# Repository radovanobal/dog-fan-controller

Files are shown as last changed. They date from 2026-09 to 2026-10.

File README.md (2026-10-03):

# Dog Fan Controller

A PWM controller for two Noctua NF-A14 PWM fans, using an ESP32-C3 SuperMini
and an external SHT4x temperature and humidity sensor.

## Licence and attribution

Copyright © 2026 **Appicanis, Radovan Obal s.p.**

The original hardware design and accompanying design documentation are
licensed under **CERN-OHL-P-2.0**. See [LICENSE](LICENSE) for the complete
licence and [NOTICE](NOTICE) for attribution, source location and scope.

You may use, modify, manufacture and sell the design, including commercially.
You do not have to publish your modifications. When redistributing design
materials, retain the applicable notices and provide the licence; when
redistributing modified design materials, also identify and date your changes.
When supplying physical products, ensure recipients can access the applicable
notices, as required by section 4 of the licence. We impose no additional
requirement for prominent branding or credit on a product or sales page.

Original design: **Appicanis, Radovan Obal s.p.**  
Source: <https://github.com/radovanobal/dog-fan-controller>

Third-party materials retain their own licences. Firmware and standalone
software require their own explicit licence; the hardware licence above
does not automatically apply to them.

## Open on another machine

Install **KiCad 10** with its standard symbol, footprint and 3D model libraries,
clone this repository, then open `Fan Controller.kicad_pro` in KiCad.
No personal library configuration or custom path variables are required.

The project library tables explicitly reference KiCad's standard libraries using
`KICAD10_SYMBOL_DIR` and `KICAD10_FOOTPRINT_DIR`. Custom dependencies are included
in `custom_footprints.pretty/`, `Fan_Controller.pretty/`, `symbols/` and
`3dmodels/`, and use `${KIPRJMOD}` paths relative to the checkout. The two
root-level symbol libraries are also registered in the project table. Standard
3D models use KiCad's `KICAD10_3DMODEL_DIR` setting.

When adding a custom part, include its symbol, footprint and any 3D model in the
repository and update the project library tables. Avoid absolute paths or
libraries registered only in your personal KiCad settings.

## Manufacturing preparation

JLCPCB fabrication and draft assembly outputs, order settings and review status
are in [manufacturing/jlcpcb](manufacturing/jlcpcb/README.md). Regenerate exports
with `python3 tools/prepare_jlcpcb.py` using KiCad 10.

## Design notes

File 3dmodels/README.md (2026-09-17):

# Custom library assets

The custom footprints, symbol libraries and STEP models bundled with this project
were copied from the existing design's local KiCad libraries on 2026-09-17.
Existing creator and manufacturer metadata are retained in the library files.
The normalized project-local fuse symbol is retained. Imported symbol default
footprint names now resolve through the project library table. Footprint model
assignments and transforms were copied from the PCB, with paths made relative to
`${KIPRJMOD}`. PCB placement, routing and model transforms are unchanged.

These third-party assets retain their original licences and notices, as described
in the repository's NOTICE; bundling does not relicense them under CERN-OHL-P-2.0.
The original local files did not include separate licence files.

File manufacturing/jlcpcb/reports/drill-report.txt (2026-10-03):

Drill report for Fan Controller.kicad_pcb
Created on 2026-09-17T20:02:06

Copper Layer Stackup:
    =============================================================
    L1 :  F.Cu                      front
    L2 :  In1.Cu                    in1
    L3 :  In2.Cu                    in2
    L4 :  B.Cu                      back

Drill file 'Fan Controller-PTH.drl' contains
    plated through holes:
    =============================================================
    T1  0.300mm  0.0118"  (38 holes))
    T2  0.750mm  0.0295"  (19 holes))
    T3  0.840mm  0.0331"  (16 holes))
    T4  1.000mm  0.0394"  (2 holes))
    T5  1.067mm  0.0420"  (8 holes))
    T6  1.550mm  0.0610"  (2 holes))

    Total plated holes count 85

Drill file 'Fan Controller-NPTH.drl' contains
    unplated through holes:
    =============================================================
    T1  1.295mm  0.0510"  (2 holes))
    T2  2.200mm  0.0866"  (4 holes))
    T3  2.700mm  0.1063"  (1 hole)

    Total unplated holes count 7

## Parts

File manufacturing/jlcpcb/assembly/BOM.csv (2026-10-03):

Comment | Designator | Footprint | LCSC Part # | Manufacturer Part Number | Manufacturer | Quantity
47µF | C1,C8,C9 | C_1210_3225Metric | C84494 | GRM32ER71A476KE15L | Murata | 3
100nF | C2,C4,C5,C13,C18 | C_0805_2012Metric | C1711 | CL21B104KBCNNNC | Samsung Electro-Mechanics | 5
22µF | C3 | CP_Elec_6.3x5.8 | C336302 | EEEHB1V220P | Panasonic | 1
100nF | C7,C14 | C_0603_1608Metric | C1591 | CL10B104KB8NNNC | Samsung Electro-Mechanics | 2
4.7µF | C10 | C_0805_2012Metric | C86040 | GRM21BR71C475KA73L | Murata | 1
10µF | C11,C12 | C_1206_3216Metric | C89632 | CL31B106KBHNNNE | Samsung Electro-Mechanics | 2
22µF / 25V | C15,C16 | C_1210_3225Metric | C3852592 | C1210C226M3RAC7800 | KEMET | 2
56pF C0G | C17 | C_0805_2012Metric | C2277731 | C0805C560G1GACTU | KEMET | 1
47µF / 25V Hybrid | C19 | CP_Elec_6.3x5.8 | C542308 | EEHZC1E470P | Panasonic | 1
SS14 | D1 | D_SMA | C47460 | SS14-E3/61T | Vishay | 1
SMCJ18A | D2 | DIOM7959X262N | C374030 | SMCJ18A | Littelfuse | 1
BZT52C12Q-7-F | D3 | D_SOD-123 | C460785 | BZT52C12Q-7-F | Diodes Inc. | 1
4.7µH | L1 | IND_SPM5030T-4R7M-HZ | C435271 | SPM5030T-4R7M-HZ | TDK | 1
15µH | L2 | IND_SPM6530T-150M-HZ | C307809 | SPM6530T-150M-HZ | TDK | 1
SQD19P06-60L_GE3 | Q1 | TO252AA_SQD19_VIS | C143665 | SQD19P06-60L_GE3 | Vishay | 1
47R | R1,R2 | R_0805_2012Metric | C114541 | RC0805FR-0747RL | Yageo | 2
100k | R3,R4 | R_0805_2012Metric | C96346 | RC0805FR-07100KL | Yageo | 2
1k | R5,R6 | R_0805_2012Metric | C95781 | RC0805FR-071KL | Yageo | 2
10k | R7,R8 | R_0805_2012Metric | C84376 | RC0805FR-0710KL | Yageo | 2
4.7k | R9,R10 | R_0805_2012Metric | C60816 | RC0805FR-074K7L | Yageo | 2
47k | R11 | R_0805_2012Metric | C126351 | RC0805FR-0747KL | Yageo | 1
422k | R12 | R_0805_2012Metric | C273967 | RC0805FR-07422KL | Yageo | 1
30.1k | R13 | R_0805_2012Metric | C163407 | RC0805FR-0730K1L | Yageo | 1
AP63205QWU-7 | U2 | SOT95P280X100-6N | C5248537 | AP63205QWU-7 | Diodes Inc. | 1
SN74LVC2G06DBVR | U3 | SOT-23-6 | C402162 | SN74LVC2G06DBVR | Texas Instruments | 1
AP63201QWU-7 | U4 | SOT95P280X100-6N | C5248535 | AP63201QWU-7 | Diodes Inc. | 1

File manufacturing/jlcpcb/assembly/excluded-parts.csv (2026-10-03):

Designator | Comment | Manufacturer Part Number | LCSC Part # | Reason
F1 | Fuse Holder | 178.6764.0001 |  | DNP in board: excluded from JLCPCB assembly
H1 | MountingHole_2.2mm_M2 |  |  | Mechanical mounting hole
H2 | MountingHole_2.2mm_M2 |  |  | Mechanical mounting hole
H3 | MountingHole_2.2mm_M2 |  |  | Mechanical mounting hole
H4 | MountingHole_2.2mm_M2 |  |  | Mechanical mounting hole
J1 | Power Input | B2B-XH-A (LF) (SN) | C158012 | DNP in board: excluded from JLCPCB assembly
J2 | 4-Pin Fan Header | 470531000 | C240840 | DNP in board: excluded from JLCPCB assembly
J3 | 4-Pin Fan Header | 470531000 | C240840 | DNP in board: excluded from JLCPCB assembly
J4 | I2C | B4B-PH-K-S (LF) (SN) | C131334 | DNP in board: excluded from JLCPCB assembly
J5 | I2C | B4B-PH-K-S (LF) (SN) | C131334 | DNP in board: excluded from JLCPCB assembly
J6 | Expansion 1 | B6B-PH-K-S (LF) (SN) | C131342 | DNP in board: excluded from JLCPCB assembly
J7 | Expansion 2 | B5B-PH-K-S (LF) (SN) | C157993 | DNP in board: excluded from JLCPCB assembly
U1 | ESP32-C3-SuperMini | ESP32-C3-SuperMini |  | DNP in board: excluded from JLCPCB assembly

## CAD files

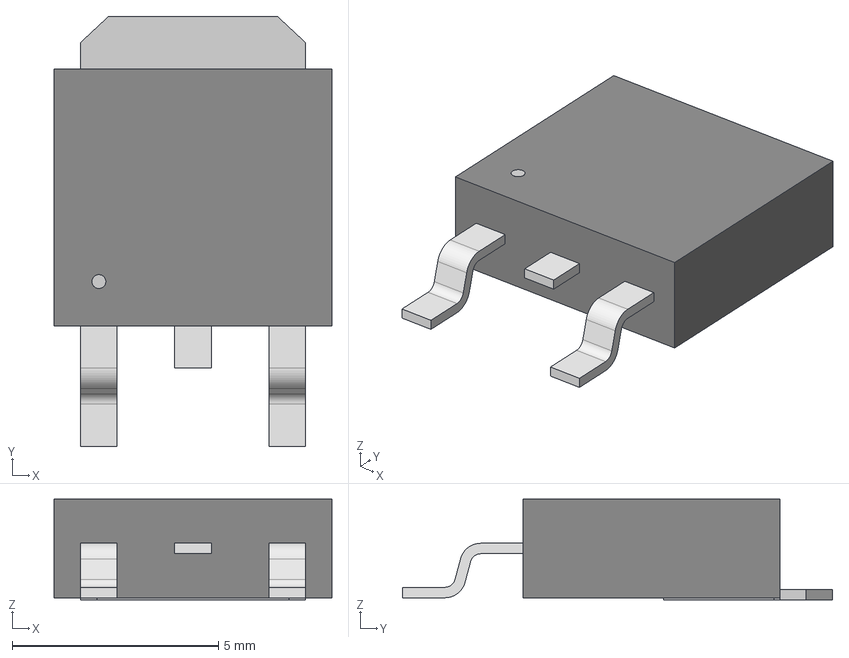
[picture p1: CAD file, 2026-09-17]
3dmodels/TO252AA_SQD19_VIS.step
6.73 x 10.4 x 2.44 mm

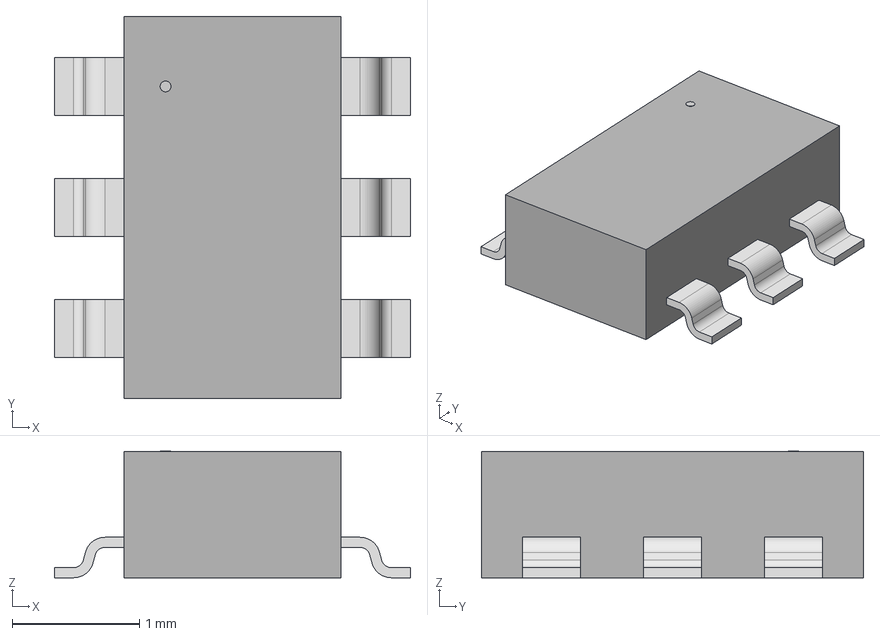
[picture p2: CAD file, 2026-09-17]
3dmodels/SOIC_05WU-7_DIO.step
2.79 x 3.00 x 0.993 mm

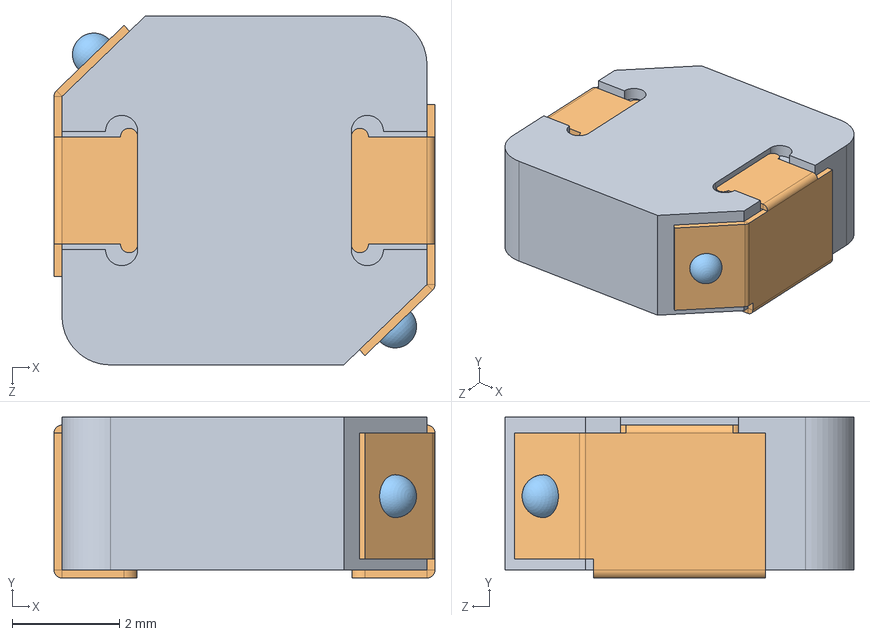
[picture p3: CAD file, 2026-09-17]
3dmodels/SPM6530T-150M-HZ.step
7.10 x 3.00 x 6.50 mm

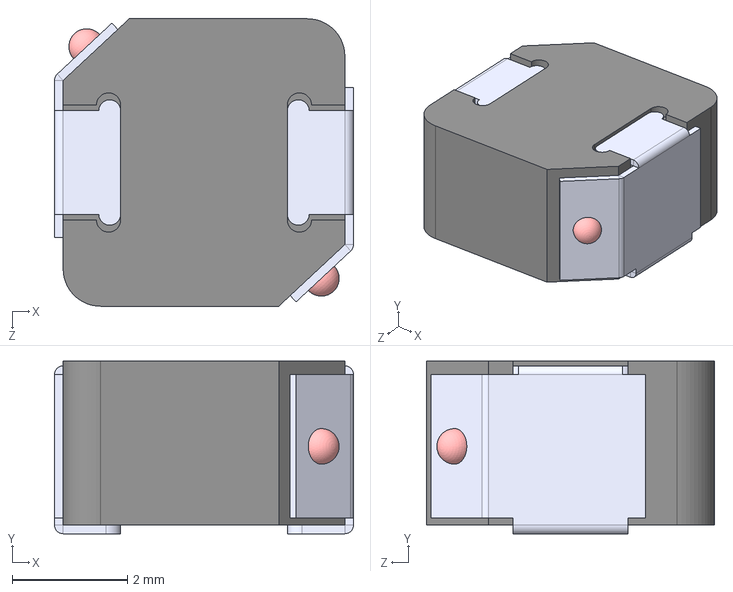
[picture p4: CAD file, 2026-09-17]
3dmodels/SPM5030T-4R7M-HZ.step
5.20 x 3.00 x 5.00 mm

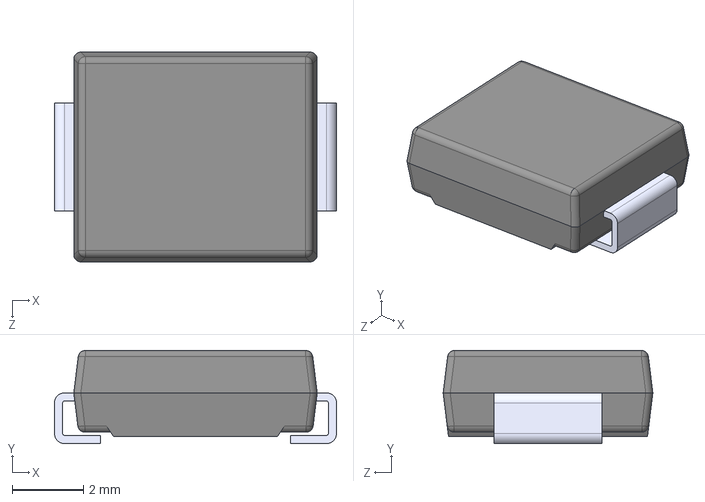
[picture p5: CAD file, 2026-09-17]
3dmodels/SMCJ18A.STEP
7.94 x 2.62 x 5.90 mm

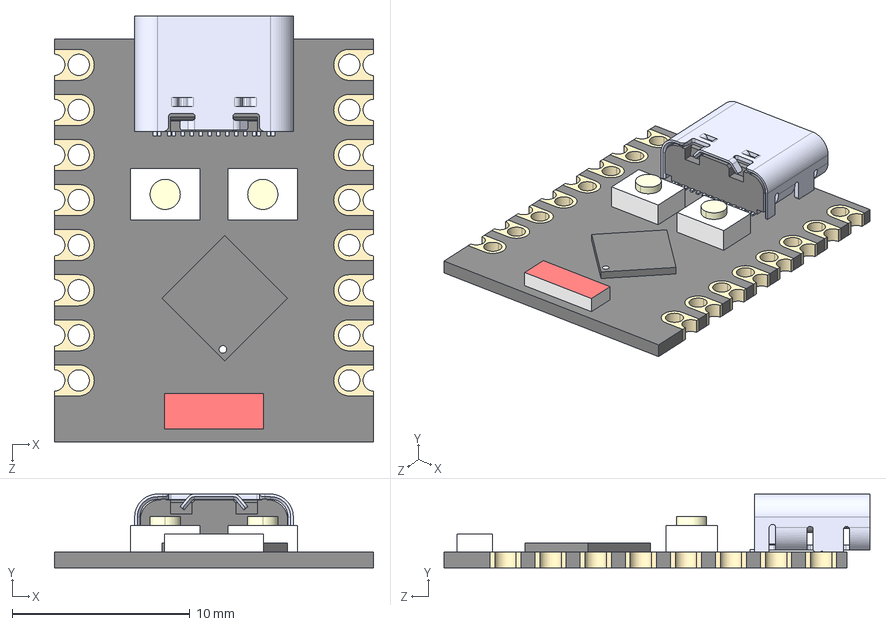
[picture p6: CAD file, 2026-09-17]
3dmodels/ESP32-C3 SuperMini--3DModel-STEP-56544.STEP
18.0 x 4.16 x 24.0 mm
Board c3mini
USB C
components (other)^ESP32-C3 SuperMini

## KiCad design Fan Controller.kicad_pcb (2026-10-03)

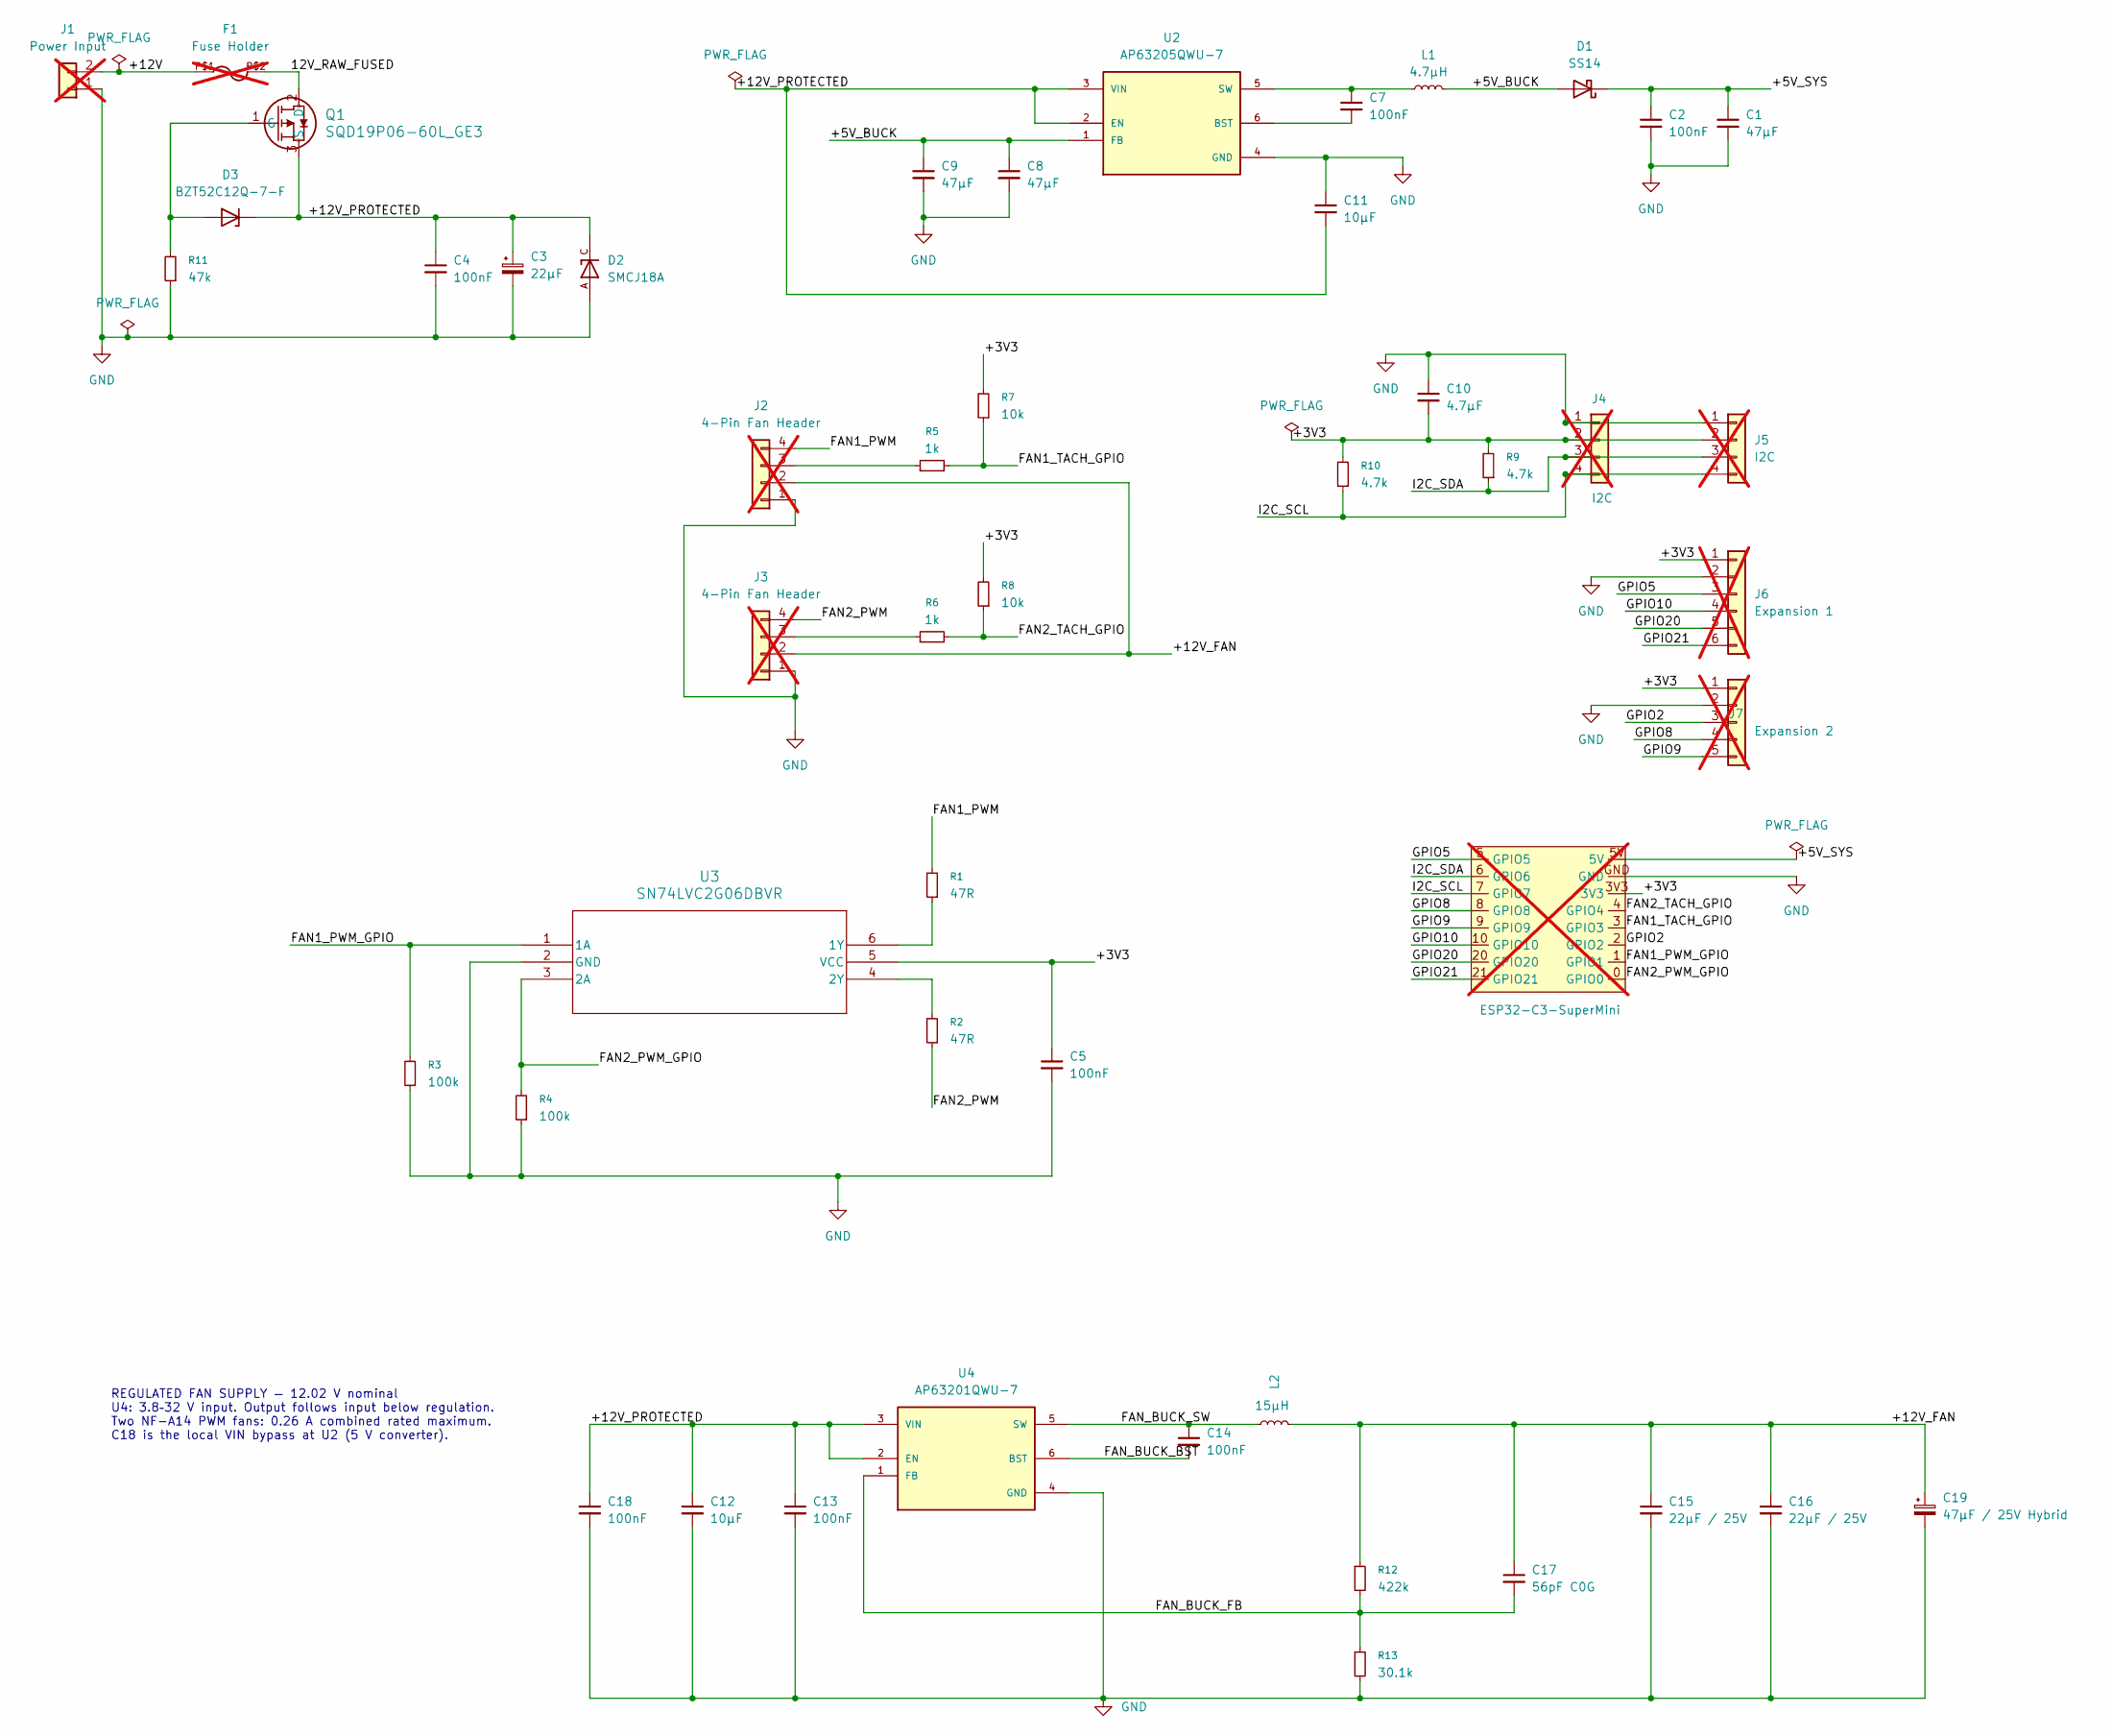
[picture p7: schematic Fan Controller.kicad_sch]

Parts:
C1, C8, C9: 47µF; C_1210_3225Metric; MPN GRM32ER71A476KE15L; LCSC C84494
C2, C4, C5, C13, C18: 100nF; C_0805_2012Metric; MPN CL21B104KBCNNNC; LCSC C1711
C3: 22µF; CP_Elec_6.3x5.8; MPN EEEHB1V220P; LCSC C336302
C7, C14: 100nF; C_0603_1608Metric; MPN CL10B104KB8NNNC; LCSC C1591
C10: 4.7µF; C_0805_2012Metric; MPN GRM21BR71C475KA73L; LCSC C86040
C11, C12: 10µF; C_1206_3216Metric; MPN CL31B106KBHNNNE; LCSC C89632
C15, C16: 22µF / 25V; C_1210_3225Metric; MPN C1210C226M3RAC7800; LCSC C3852592
C17: 56pF C0G; C_0805_2012Metric; MPN C0805C560G1GACTU; LCSC C2277731
C19: 47µF / 25V Hybrid; CP_Elec_6.3x5.8; MPN EEHZC1E470P; LCSC C542308
D1: SS14; D_SMA; MPN SS14-E3/61T; LCSC C47460
D2: SMCJ18A; DIOM7959X262N; PARTREV 11/20/15; LCSC C374030
D3: BZT52C12Q-7-F; D_SOD-123; MPN BZT52C12Q-7-F; LCSC C460785
F1: Fuse Holder; LITTLEFUSE_178.6764.0001; MPN 178.6764.0001; not fitted
J1: Power Input; JST_XH_B2B-XH-A_1x02_P2.50mm_Vertical; MPN B2B-XH-A (LF) (SN); LCSC C158012; not fitted
J2, J3: 4-Pin Fan Header; CONN_SD-47053-001_H10P00_MOL; MPN 470531000; LCSC C240840; not fitted
J4, J5: I2C; JST_PH_B4B-PH-K_1x04_P2.00mm_Vertical; MPN B4B-PH-K-S (LF) (SN); LCSC C131334; not fitted
J6: Expansion 1; JST_PH_B6B-PH-K_1x06_P2.00mm_Vertical; MPN B6B-PH-K-S (LF) (SN); LCSC C131342; not fitted
J7: Expansion 2; JST_PH_B5B-PH-K_1x05_P2.00mm_Vertical; MPN B5B-PH-K-S (LF) (SN); LCSC C157993; not fitted
L1: 4.7µH; IND_SPM5030T-4R7M-HZ; MPN SPM5030T-4R7M-HZ; LCSC C435271
L2: 15µH; IND_SPM6530T-150M-HZ; MPN SPM6530T-150M-HZ; LCSC C307809
Q1: SQD19P06-60L_GE3; TO252AA_SQD19_VIS; MPN SQD19P06-60L_GE3; LCSC C143665
R1, R2: 47R; R_0805_2012Metric; MPN RC0805FR-0747RL; LCSC C114541
R3, R4: 100k; R_0805_2012Metric; MPN RC0805FR-07100KL; LCSC C96346
R5, R6: 1k; R_0805_2012Metric; MPN RC0805FR-071KL; LCSC C95781
R7, R8: 10k; R_0805_2012Metric; MPN RC0805FR-0710KL; LCSC C84376
R9, R10: 4.7k; R_0805_2012Metric; MPN RC0805FR-074K7L; LCSC C60816
R11: 47k; R_0805_2012Metric; MPN RC0805FR-0747KL; LCSC C126351
R12: 422k; R_0805_2012Metric; MPN RC0805FR-07422KL; LCSC C273967
R13: 30.1k; R_0805_2012Metric; MPN RC0805FR-0730K1L; LCSC C163407
U1: ESP32-C3-SuperMini; MPN ESP32-C3-SuperMini; not fitted
U2: AP63205QWU-7; SOT95P280X100-6N; PARTREV 1 - 2; LCSC C5248537
U3: SN74LVC2G06DBVR; SOT-23-6; MPN SN74LVC2G06DBVR; LCSC C402162
U4: AP63201QWU-7; SOT95P280X100-6N; PARTREV 1 - 2; LCSC C5248535

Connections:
/12V_RAW_FUSED: F1.P$2, Q1.2 (D)
/+3V3: C5.1, C10.2, J4.2, J5.2, J6.1, J7.1, R7.2, R8.2, R9.2, R10.2, U1.3V3, U3.5 (VCC)
/+5V_BUCK: C8.1, C9.1, D1.2 (A), L1.2, U2.1 (FB)
/+5V_SYS: C1.1, C2.1, D1.1 (K), U1.5V
/+12V: F1.P$1, J1.2
/+12V_FAN: C15.1, C16.1, C17.1, C19.1, J2.2, J3.2, L2.2, R12.1
/+12V_PROTECTED: C3.1, C4.1, C11.2, C12.1, C13.1, C18.1, D2.C, D3.1 (K), Q1.3 (S), U2.2 (EN), U2.3 (VIN), U4.2 (EN), U4.3 (VIN)
/FAN1_PWM: J2.4, R1.2
/FAN1_PWM_GPIO: R3.2, U1.1 (GPIO1), U3.1 (1A)
/FAN1_TACH_GPIO: R5.2, R7.1, U1.3 (GPIO3)
/FAN2_PWM: J3.4, R2.1
/FAN2_PWM_GPIO: R4.2, U1.0 (GPIO0), U3.3 (2A)
/FAN2_TACH_GPIO: R6.2, R8.1, U1.4 (GPIO4)
/FAN_BUCK_BST: C14.2, U4.6 (BST)
/FAN_BUCK_FB: C17.2, R12.2, R13.1, U4.1 (FB)
/FAN_BUCK_SW: C14.1, L2.1, U4.5 (SW)
/GPIO2: J7.3, U1.2 (GPIO2)
/GPIO5: J6.3, U1.5 (GPIO5)
/GPIO8: J7.4, U1.8 (GPIO8)
/GPIO9: J7.5, U1.9 (GPIO9)
/GPIO10: J6.4, U1.10 (GPIO10)
/GPIO20: J6.5, U1.20 (GPIO20)
/GPIO21: J6.6, U1.21 (GPIO21)
/I2C_SCL: J4.4, J5.4, R10.1, U1.7 (GPIO7)
/I2C_SDA: J4.3, J5.3, R9.1, U1.6 (GPIO6)
GND: C1.2, C2.2, C3.2, C4.2, C5.2, C8.2, C9.2, C10.1, C11.1, C12.2, C13.2, C15.2, C16.2, C18.2, C19.2, D2.A, J1.1, J2.1, J3.1, J4.1, J5.1, J6.2, J7.2, R3.1, R4.1, R11.1, R13.2, U1.GND, U2.4 (GND), U3.2 (GND), U4.4 (GND)
unnamed: D3.2 (A), Q1.1 (G), R11.2
unnamed: J2.3, R5.1
unnamed: J3.3, R6.1
unnamed: C7.2, U2.6 (BST)
unnamed: C7.1, L1.1, U2.5 (SW)
unnamed: R1.1, U3.6 (1Y)
unnamed: R2.2, U3.4 (2Y)

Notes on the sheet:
REGULATED FAN SUPPLY — 12.02 V nominal U4: 3.8–32 V input. Output follows input below regulation. Two NF-A14 PWM fans: 0.26 A combined rated maximum. C18 is the local VIN bypass at U2 (5 V converter).

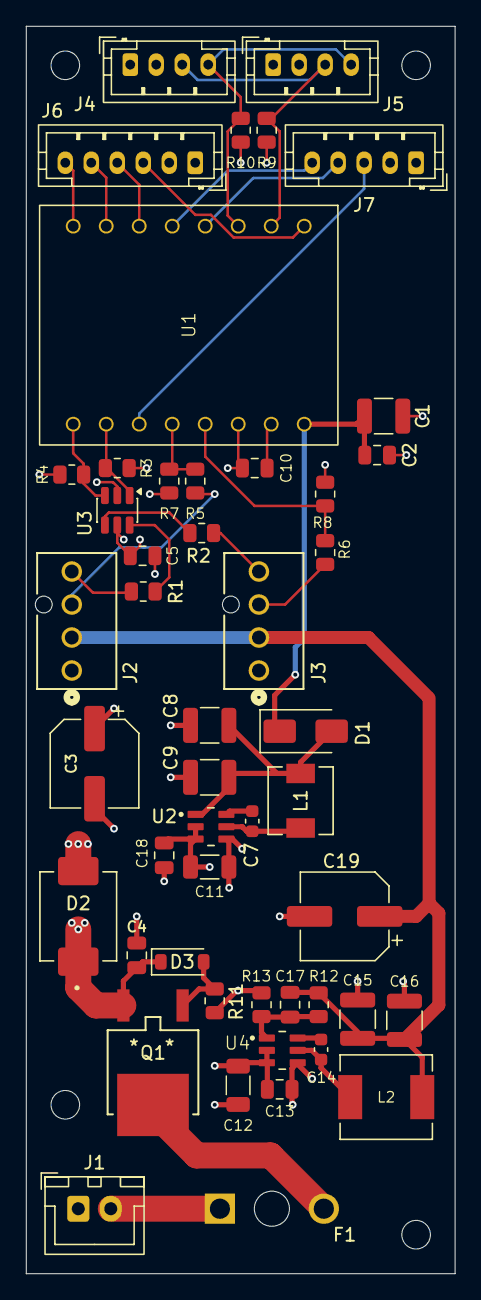
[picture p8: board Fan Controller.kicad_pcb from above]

Board: 4 copper layers, 33.0 x 96.0 mm, 53 parts (0 on the bottom side), 33 nets.

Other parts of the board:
H1, H2, H3, H4: MountingHole_2.2mm_M2

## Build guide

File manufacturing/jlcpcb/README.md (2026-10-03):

# JLCPCB preparation — Dog Fan Controller

Prepared 2026-09-17 with KiCad 10.0.5. This package is for quotation and review;
no order has been submitted. Assembly part availability and vendor orientation
matching are not yet verified.

## Files to upload

- `Dog-Fan-Controller-Gerbers.zip`: 11 Gerber layers plus separate PTH and NPTH
  Excellon drill files, all using the same absolute origin. No drawings or
  validation reports are included in the ZIP.
- `assembly/BOM.csv`: draft top-side assembly BOM, 40 components / 26 part numbers.
- `assembly/CPL.csv`: matching 40 placements in millimetres, with KiCad rotations
  normalized to 0–360 degrees. Coordinates use the same absolute origin as the
  fabrication data; negative Y coordinates are intentional.
- `assembly/excluded-parts.csv`: nine DNP components and four mechanical holes.
  F1, J1–J7 and U1 are excluded from JLCPCB assembly according to the board flags.
  U1 is explicitly marked for hand population. Confirm the other exclusions in
  the assembly preview; DNP here does not mean these parts are unnecessary for
  the completed controller.
- `previews/`: independent Gerber renders of the top, bottom and inner layers.
- `reports/`: DRC, ERC, drill inventory, Gerber parsing results and source/output
  SHA-256 hashes. These are review records, not fabrication layers.

## PCB order settings

| Setting | Value |
|---|---|
| Layers | 4: F.Cu → In1.Cu → In2.Cu → B.Cu |
| Finished outline | 33 × 96 mm (outline centreline dimensions) |
| Material / nominal thickness | FR-4 / 1.6 mm |
| Outer copper | 1 oz |
| Inner copper | 0.5 oz — accepted for the stated fan/controller load |
| Stackup | Standard JLC04161H-7628 / published “No requirement” construction |
| Impedance control | No controlled-impedance requirement identified in this design |
| Via covering | Tented on both sides as exported |
| Holes | 85 plated, including 38 vias; 7 non-plated |
| Smallest drill / via diameter | 0.30 mm / 0.60 mm |
| Minimum routed track width | 0.20 mm |
| Quantity, solder-mask colour, finish | Still to select in the quotation |

The board metadata now follows JLCPCB's published construction: 35 µm outer
copper, 15.2 µm inner copper, two 0.2104 mm prepregs and a 1.065 mm dielectric
core. Overall board thickness remains nominally 1.6 mm. Published nominal layer
thicknesses and solder mask do not sum to exactly 1.6000 mm; factory finished
thickness tolerance applies. Confirm the construction offered in the quote.

## Copper/current assessment

The stated load is the two fans plus the buck-powered controller, with no
additional expansion-header power loads specified. The README identifies
standard 12 V Noctua NF-A14 PWM fans; Noctua rates these at 0.13 A maximum each
(0.26 A combined). This assumption does not cover industrialPPC or 5 V variants.

The current layout has a continuous GND island on In1.Cu, and separate continuous
3.3 V and protected-input-12 V islands on In2.Cu. The protected-input plane feeds
the two buck converters. Fan-rail and 5 V output distribution is routed on the
outer layers, which retain 1 oz copper. Zone thermal spokes are 0.5 mm wide.

For scale, using copper resistivity 1.724e-8 Ω·m at 20°C, a 100 mm-long,
5 mm-wide strip of 15.2 µm copper has R ≈ 22.7 mΩ. At 2 A this is approximately
45 mV drop and 91 mW loss; at 60°C resistance rises to about 26.2 mΩ. The main
planes are much wider, apart from local pad/via connections. This illustrative
strip calculation and inspection support using standard inner copper for the
stated load. It is not an extracted resistance network or a temperature-rise
simulation, and does not rate the entire assembly for 2 A continuous output from
each regulator. Regulator cooling, external traces, vias, fuse coordination and
transient performance have separate limits. Check temperatures and rail voltages
on the first powered prototype under maximum intended load.

## Verification and remaining review

- Current project DRC: zero board violations and zero unconnected items.
- ERC: zero violations.
- Schematic parity: four extra-footprint notices for mechanical mounting holes
  H1–H4, with no electrical component mismatch.
- DRC uses the project's configured checks. `reports/drc.json` lists ignored
  checks; this is not a blanket manufacturer DFM certification.
- Independent Gerbonara parsing recognizes four copper layers and all technical
  layers, with 85 PTH and 7 NPTH drill hits. Gerber outlines align with the board
  and drill coordinates. KiCad's 0.05 mm outline stroke makes the rendered
  bounding box 33.05 × 96.05 mm; the intended cut follows its 33 × 96 mm centreline.
- No copper routing or component placement was changed while preparing exports;
  only stackup material/thickness metadata changed.
- Check the JLCPCB Gerber preview and layer order before accepting the quote.
- Review silkscreen legibility: the R9/R10 labels are crowded in the top preview.
- Confirm each LCSC number against the manufacturer part, package, ratings and
  live assembly stock. The supplied IDs are copied from the design, not verified
  against current inventory. No substitutions have been made.
- Review component origins and rotations in JLCPCB's placement preview,
  especially U2–U4, Q1, D1–D3, C3 and C19. KiCad rotation conventions can differ
  from the vendor library. No undocumented rotation offsets were applied.
- Final quantity, finish, colour, assembly scope, and any tooling rails/fiducials
  required by the selected assembly service remain quotation decisions.

## Regenerate

Install KiCad 10 and Python 3, then run from the repository:

```sh
python3 tools/prepare_jlcpcb.py
```

Use `--kicad-cli /path/to/kicad-cli` when it is not on PATH. The script runs DRC
and ERC, exports Gerbers/drills/positions, rebuilds the BOM/CPL and ZIP, and records
source/output hashes. It refuses unexpected DRC/ERC/parity findings and incomplete
assembly IDs. It does not modify source board or schematic files. Previews and
independent parser reports are a separate snapshot and should be refreshed after
geometry edits; they are not regenerated by this export script.

## References checked 2026-09-17

- [JLCPCB KiCad Gerber/drill guide](https://jlcpcb.com/help/article/how-to-generate-gerber-and-drill-files-in-kicad-9)
- [JLCPCB BOM format](https://jlcpcb.com/help/article/bill-of-materials-for-pcb-assembly)
- [JLCPCB placement format](https://jlcpcb.com/help/article/pick-place-file-for-pcb-assembly)
- [JLCPCB capabilities](https://jlcpcb.com/capabilities/pcb-capabilities)
- [JLCPCB published stackups](https://jlcpcb.com/impedance)
- [Noctua NF-A14 PWM specifications](https://www.noctua.at/en/products/nf-a14-pwm/specifications)
- [Diodes AP63205Q family](https://www.diodes.com/part/AP63205Q/)

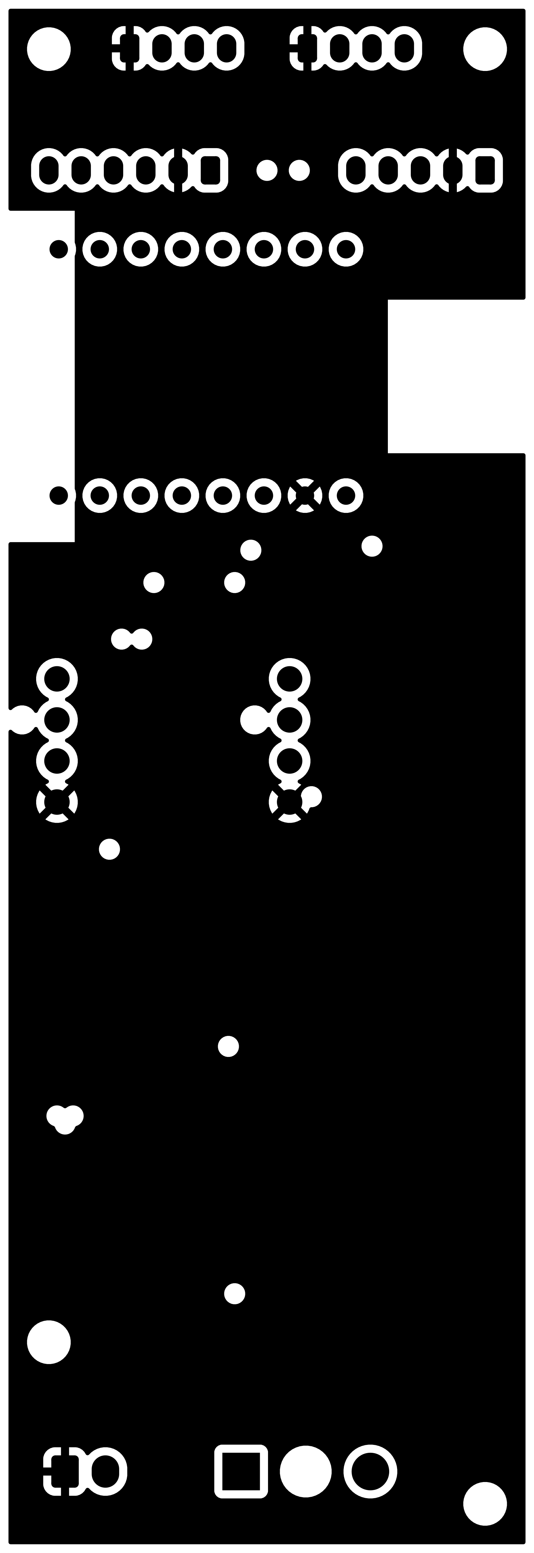
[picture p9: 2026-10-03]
manufacturing/jlcpcb/previews/inner_1.png

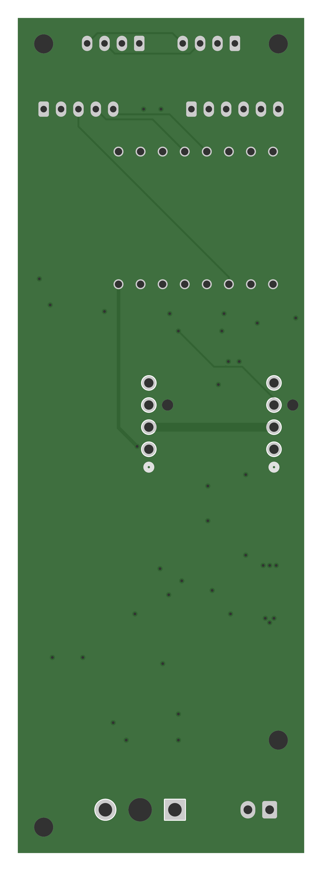
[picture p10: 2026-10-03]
manufacturing/jlcpcb/previews/bottom.png

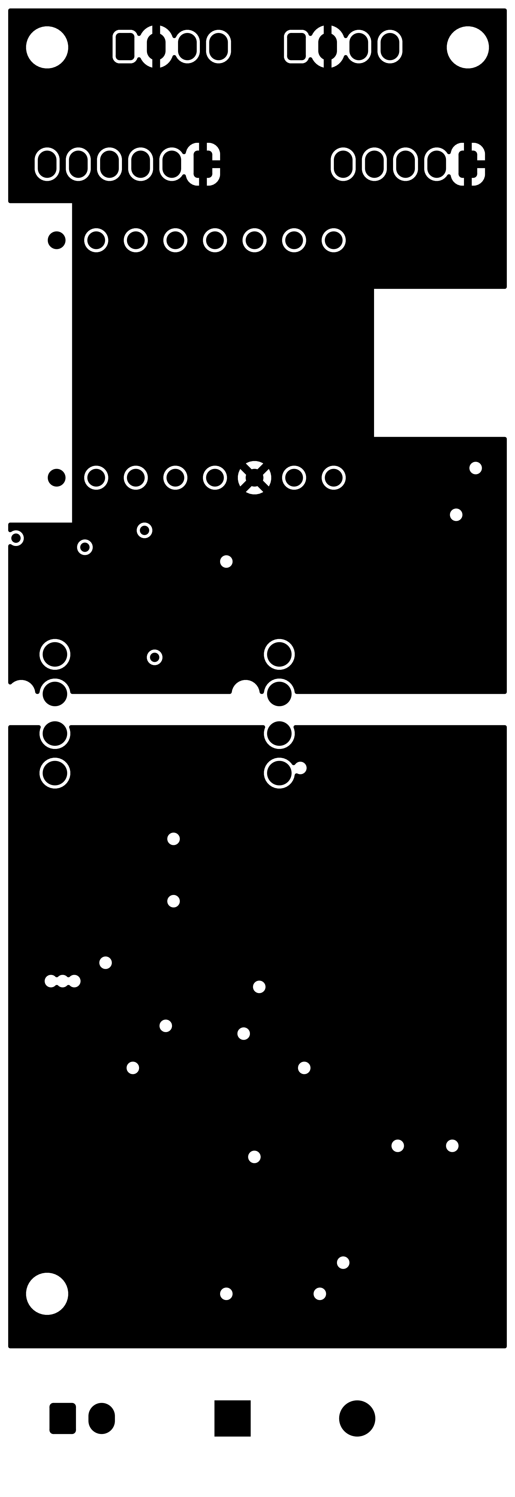
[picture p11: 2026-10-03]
manufacturing/jlcpcb/previews/inner_2.png

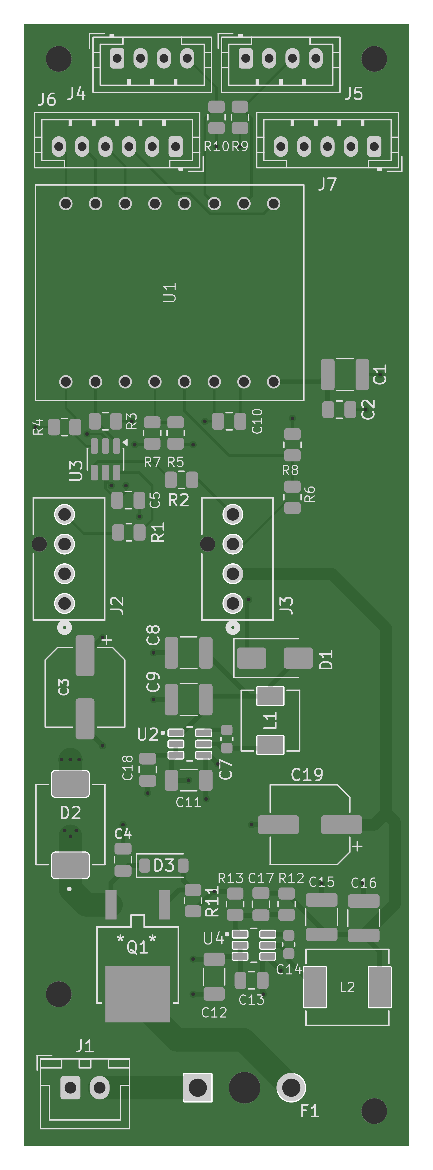
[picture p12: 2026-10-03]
manufacturing/jlcpcb/previews/top.png

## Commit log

2026-08-31 Init commit
    [Fan Controller.kicad_pcb, Fan Controller.kicad_sch]
2026-09-05 Schematic finished, base PCB fit checked
    [Fan Controller.kicad_pcb, Fan Controller.kicad_sch]
2026-09-05 PCB: fix L1 land pattern, move F1 outline off copper, re-place all sections
    [Fan Controller.kicad_pcb]
2026-09-05 PCB: normalize silk text angles, add antenna keepout annotation
    [Fan Controller.kicad_pcb]
2026-09-05 PCB: rotate U1 180 deg so antenna faces board edge, clear USB corridor
    [Fan Controller.kicad_pcb]
2026-09-05 PCB: optimization pass - tighten critical loops, align rows, fix silk ref overlaps
    [Fan Controller.kicad_pcb]
2026-09-05 silk reposition, overlap fix
    [Fan Controller.kicad_pcb]
2026-09-06 Routed the placements
    [Fan Controller.kicad_pcb]
2026-09-06 Schematic optimisations
    [Fan Controller.kicad_pcb, Fan Controller.kicad_sch]
2026-09-06 Better placement of R11
    [Fan Controller.kicad_pcb]
2026-09-06 Improvements around U2 placements
    [Fan Controller.kicad_pcb, Fan Controller.kicad_sch]
2026-09-09 Corrections in routing, optimizations
    [Fan Controller.kicad_pcb]
2026-09-10 Better buck power reliability. Better placement of some distant elements.
    [Fan Controller.kicad_pcb, Fan Controller.kicad_sch]
2026-09-13 R1 and 2 were 47k items added to manufacturing instead of 47R
    some placement optimizations
    [Fan Controller.kicad_pcb, Fan Controller.kicad_sch]
2026-09-14 Redesigned the 3V3 layout resulting in a much neater trace run. Widened the power rails
    [Fan Controller.kicad_pcb, Fan Controller.kicad_sch]
2026-09-17 Restore footprint settigns add missing repo footprints add missing 3d elements
    [ESP32-C3 SuperMini--3DModel-STEP-56544.STEP, Fan Controller.kicad_pcb, Fan Controller.kicad_sch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]
2026-10-03 some placement fix
    [BOM.csv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]
